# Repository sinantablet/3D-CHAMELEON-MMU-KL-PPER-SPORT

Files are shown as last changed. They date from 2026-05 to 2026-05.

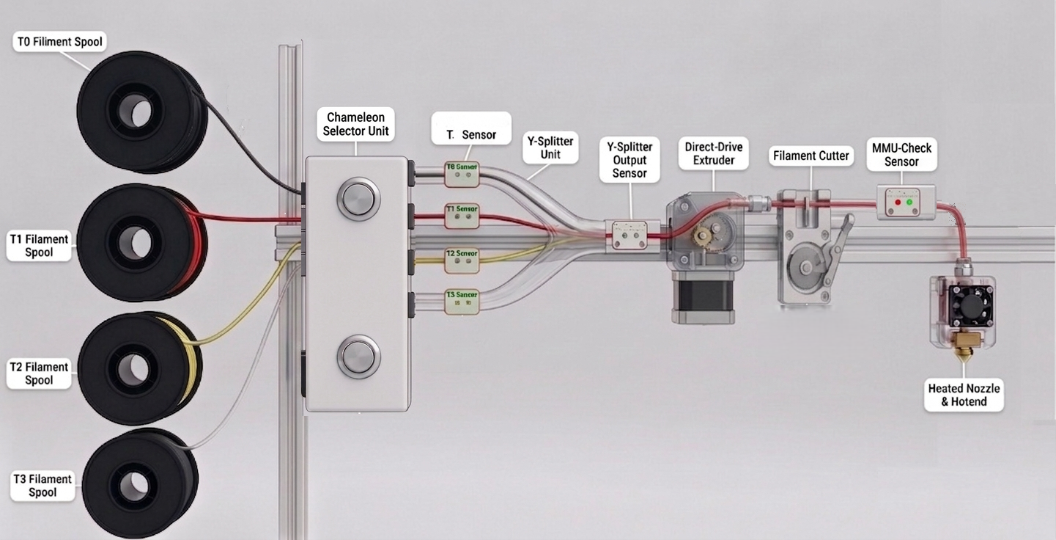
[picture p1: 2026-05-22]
mmu şema.jpg

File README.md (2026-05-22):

Klipper Tabanlı Akıllı Çoklu Filament Yönetim Sistemi (MMU)
Bu proje; stock chameleon elektronik kontrol kartına ihtiyaç duymadan, yalnızca 1 adet standart 3D yazıcı anakartı, 6 adet mikro-anahtar (switch/sensör) ve 1 adet mekanik filament kesici kullanarak Klipper üzerinde çalışan 4 renkli (T0-T3) akıllı bir filament yönetim sistemi modifikasyonudur.

Sistem; baskı güvenliğini artırmak, tıkanmaları önlemek ve renk geçişleri ile baskı sonunu tamamen otomatikleştirmek için tasarlanmıştır.

🛠 Donanım Mimarisi ve Sensör Yerleşimi
Sistemde kullanılan 6 adet optik veya mekanik siviç, anakart üzerindeki boş endstop (limit anahtarı) pinlerine bağlanır. Sensörlerin fiziksel konumları ve görevleri şu şekildedir:

A. Takım Giriş Sensörleri (4 Adet)
Konum: T0, T1, T2 ve T3 filament hatlarının tam giriş noktaları.

Görevi: Hangi takıma manuel filament yüklendiğini algılar, otomatik motor senkronizasyonunu başlatır ve ilgili hattaki filamentin bitip bitmediğini (Runout) kontrol eder.

B. Extruder Giriş Sensörü (1 Adet)
Konum: Extruder dişlilerinin hemen girişi (Hotend öncesi).

Görevi: Takımlardan gelen filamentin extruder girişine başarıyla ulaştığını doğrular.

C. Extruder Çıkış Sensörü (1 Adet)
Konum: Extruder dişlilerinin hemen çıkışı.

Görevi: Baskı esnasında gerçek zamanlı malzeme akışını izler. Motor döndüğü halde buradan filament geçmiyorsa, makara takılması veya patinaj (sıkışma) durumunu algılayarak sistemi kurtarma moduna alır.

D. Mekanik Filament Kesici (1 Adet)
Konum: Extruder mekanizmasının hemen altı (Hotend girişinin üstü).

Görevi: Baskı bittiğinde veya renk değişimlerinde filament ucunu keserek pürüzsüz bir tahliye sağlar; hotend içinde malzeme donmasını ve tıkanmayı engeller.

🚀 6 Aşamalı Akıllı Çalışma Mantığı
Sistem, Klipper makroları ve bu 6 sensörün anlık durum bilgileriyle tamamen otomatik bir döngü yönetir:

Bu sistem; çok renkli ve çok malzemeli (Multi-Material) 3D yazıcı ekosistemlerinde, baskı sürecinin kesintisiz sürmesini sağlamak, kullanıcı hatalarını en aza indirmek, donanım güvenliğini korumak ve baskı sonrasını tamamen otomatikleştirmek adına geliştirilmiş altı aşamalı bir akıllı yönetim mimarisine sahiptir.

1. Başlangıç Kalibrasyonu ve Güvenli Tahliye Protokolü

Sistem ilk enerji aktivasyonunu gerçekleştirdiğinde,Eğer besleme yollarında veya extruder gövdesinde önceden kalmış bir filament algılanırsa, olası sıkışmaları ve nozzle tıkanmalarını önlemek adına otomatik boşaltma algoritması devreye girer. Sistem, eriyik bölgedeki malzemeyi 200 derecede ve güvenli bir şekilde geri çekerek sistemi temizler ve mekanik bileşenleri başlangıç (Home) konumuna getirir.

2. Ardışık Takım Kontrolü ve Ön Yükleme Senkronizasyonu

İlk açılış rutinlerinin ardından, sistem bünyesindeki tüm filament sürücü takımları (T0, T1, T2, T3) sırayla elektronik ve mekanik teste tabi tutulur. Doğrulama sürecinde, aktif hatlardaki filamentler hızlandırılarak önceden belirlenmiş referans bekleme konumuna (hazırda bekletme noktası) otomatik olarak sürülür. Bu sayede renkli yazdırma için filament ler hazır konumda bekletiilir.

3. Dinamik Filament Sonu Algılama ve Otomatik Güvenli Park (Runout)

Baskı esnasında herhangi bir takımdaki filament tükendiğinde veya koptuğunda, hat üzerindeki mikro-sensörler durumu anlık olarak ana karta bildirir. Sistem, baskıyı kusursuz şekilde sürdürebilmek adına "Görüntü ve Pozisyon Koruma" moduna geçer: Kafayı güvenli bir koordinata park eder, ısı değerlerini optimize eder ve kullanıcıdan manuel otomotik yeni filament yüklemesi beklemek üzere sistemi askıya (Pause) alır.

4. Akıllı Manuel Besleme Sonrası Otomatik Takım Eşleştirme

Baskı askıdayken veya yazıcı hazır konumdayken, kullanıcının boşalan takımlardan herhangi birine manuel olarak filament yerleştirmesi sistem tarafından dinamik olarak izlenir. Filamentin ilgili giriş sensöründen geçmesiyle birlikte, sistem hangi takıma müdahale edildiğini akıllıca algılar, o kanala ait motor sürücüsünü aktif konuma getirir ve filamenti el gücüne gerek kalmadan otomatik olarak kavrayıp başlangıç pozisyonuna ilerletir.

5. Ekstrüzyon Sonrası Geri Besleme ve Akıllı Sıkışma Döngüsü (Anti-Jam)
Yazdırma işlemi esnasında filament varlığı, sadece giriş anında değil, extruder dişlilerinin hemen sonrasında da anlık olarak kontrol edilir. Eğer motor dönmesine rağmen extruder çıkışındaki sensörden malzeme akışı algılanmazsa, sistem bunu bir "makara takılması" veya "besleme kaçırma" hatası olarak yorumlar. Sistem, baskıyı hemen durdurmak yerine malzemeyi geri çekip tekrar ileri sürmeyi deneyerek 2 kez otomatik yükleme döngüsü başlatır. Hata çözülmezse donanım güvenliği için sistemi korumalı duraklatma moduna alır. sorun giderildikten sonra baskıya devem edilebilir.

6. Otomatik Baskı Sonu Boşaltma ve Sonraki Baskıya Hazırlık Protokolü
Baskı başarıyla tamamlandığı an, sistem eritme potasını ve filament yolunu bir sonraki işe sıfır hata ile hazırlamak için TOOL_OUT makrosunu tetikler. Bu protokol sırasıyla; filament kesme (filament cut) mekanizmasını çalıştırır, extruder içinde kalan erimiş veya kesilmiş malzemeyi tahliye eder (extruder unload) ve son olarak aktif olan takım hangisi ise o takıma ait filamenti güvenli başlangıç (home) konumuna geri çeker. Böylece bir sonraki baskı öncesinde elle müdahaleye gerek kalmaz.

Filament Cut: Mekanik kesici aktif hat üzerindeki filamenti keser.

Extruder Unload: Extruder içinde kalan parça eritilerek tahliye edilir.

Tool Park: Aktif olan takım hangisi ise, o hattın filamenti bir sonraki baskıya hazır olmak üzere kendi başlangıç konumuna geri çekilir.

🎛 Dilimleyici (Slicer) Kurulumu

Sistemin baskı ilk başladığında donanımı ve filament yollarını senkronize eden akıllı protokolümüz TOOL_INIT makrosudur.
(OrcaSlicer, PrusaSlicer, Bambu Studio vb.) Printer Settings -> start g-code  ( TOOL_INIT )
Sistemin baskı sonu otomasyonunu tetikleyebilmesi için dilimleyici yazılımınızın (OrcaSlicer, PrusaSlicer, Bambu Studio vb.) Printer Settings -> end g-code  ( TOOL_OUT  TS0 )

yazıcı ayarlarından -> çoklu malzeme -> tek extruder çoklu mazleme kurulumu
çoklu mazleme sekmesinden -> pirme kulesini aktif edin.

🎛Yazıcı ayarı
printer.cfg dosyanızın ilk satırna  
[include chameleon.cfg] 
ekleyin

######################################################       ####################################################################

                                                  MAKRO AYAR VE DEĞERLERİ

--------------------------------------------------------------------------------

pin çıkışlarını kendi bord unuza göe ayarlayınız

[manual_stepper selector]
step_pin: nano:PE0
dir_pin: nano:PB9
microsteps: 1
rotation_distance: 2
enable_pin: !nano:PE1
endstop_pin: !nano:PA2  
velocity: 20      
accel: 20      
position_endstop: 15

[manual_stepper chameleon]
step_pin: nano:PB5
dir_pin: nano:PB4
microsteps: 16
rotation_distance: 41
enable_pin: !nano:PB8
endstop_pin: nano:PE6   ( bu pin önemli CHAMELEON_EXTRUDER_SMART_LOAD buradaki pine edn step yaparak filament konumu ayaralıyor)
position_endstop: 0

sensör pinleriniz anakartınıza göre ayarlayınız..

[filament_switch_sensor tool_0_sensor]
switch_pin: nano:PA15
pause_on_runout: True

[filament_switch_sensor tool_1_sensor]
switch_pin: nano:PA12
pause_on_runout: True

[filament_switch_sensor tool_2_sensor]
switch_pin: nano:PA14
pause_on_runout: True

[filament_switch_sensor tool_2_sensor]
switch_pin: nano:PA13
pause_on_runout: True

[filament_switch_sensor mmu_check]
switch_pin: nano:PB2
pause_on_runout: False

--------------------------------------------------------------------------------

[gcode_macro TOOL_INIT]
description: Homes the tool selector. Needed before any tool change.
variable_tool: 0
variable_ysplit_distance: 100
variable_chameleon_speed: 40
variable_chameleon_acc: 40
gcode:
  MANUAL_STEPPER STEPPER=selector SET_POSITION=0 
  MANUAL_STEPPER STEPPER=selector MOVE=-1.40
  MANUAL_STEPPER STEPPER=selector SET_POSITION=0 
  MANUAL_STEPPER STEPPER=selector MOVE=0.12
  MANUAL_STEPPER STEPPER=selector SET_POSITION=0 
  MANUAL_STEPPER STEPPER=chameleon SET_POSITION=0

---->variable_ysplit_distance: 100  dğerini filamnet hub ölçünüze göre ayarlaryın yspit

----->MANUAL_STEPPER STEPPER=selector MOVE=-1.40      ( bu değeri elle konsola deneyerek girnizi -1 den  -2 ye kadar deneyin selktör şaftı üzerindeki çıkıntının paralel konumu sizin başlangıç açınız olacakrtır.

------------------------------------------------------------------------------------------

[gcode_macro FILAMENT_CUT]
description: Filament kesme, tamamen otomatik güvenli Z
gcode:
  {% set F = params.F|default(6000)|int %}
  {% set current_z = printer.toolhead.position.z %}
  {% set max_model_z = params.model_z|default(current_z)|float %}
  {% set Z_safe = [current_z + 5, max_model_z + 5]|max %}

  G90 
  G1 Z{Z_safe} F3000
  G1 X290 Y290 F{F}

  G92 E0
  G1 E-2 F300
  G92 E0
  G1 E-90 F2500
  G92 E0; 
  G1 X300 Y290 F4000  
  G1 X250 Y299 F4000
  G1 X300 Y299 F4000
  G1 X290 Y290 F4000
  M117 "Filament kesildi"
  G92 E0  

filamnet kesme konumunuzu ve filamnet kesiciye çekme ölçünüzü yazıcınıza yapısına göre ayarlayınız

----->  G1 E-90 F2500 
nuzell ucu ile kesici bıcak arasındaki mesafenizi giriniz bu değer filamet ucundan 2 mm olacak şekilde ayarlanırsa filameet atığınız azalır

kesme konumu ve kesme hareketleri
---->G1 X290 Y290 F{F}

  G1 X300 Y290 F4000  
  G1 X250 Y299 F4000
  G1 X300 Y299 F4000
  G1 X290 Y290 F4000

  -----------------------------------------------------------------------------

[gcode_macro TOOL_SELECT]
gcode:
  {% set TOOL = params.TOOL|int %}
  {% set SELECTOR_SPEED = 20 %}
  M117 "Setting tool to TOOL{TOOL}"

  {% if TOOL == 0 %}
    MANUAL_STEPPER stepper=selector MOVE=0
  {% elif TOOL == 1 %}
    MANUAL_STEPPER stepper=selector MOVE=-4.5
  {% elif TOOL == 2 %}
    MANUAL_STEPPER stepper=selector MOVE=-9.5
  {% elif TOOL == 3 %}
    MANUAL_STEPPER stepper=selector MOVE=-12.5
  {% endif %}
  SET_GCODE_VARIABLE MACRO=TOOL_INIT VARIABLE=tool VALUE={TOOL}

her takımın konumunu konsoldan  MANUAL_STEPPER stepper=selector MOVE=0  manuel olarakdeğer girerek tespit edin
t0 t1 t2 t3 takım yolu açılarını bulunuz ve sisteme kayıt ediniz. açı değerleinin sağlıklı olduğundan emin olun filamneti yol seçimleri belirlediğiniz bu değerlere göre yapılacaktır.

--->MANUAL_STEPPER stepper=selector MOVE=0
--->MANUAL_STEPPER stepper=selector MOVE=-4.5
--->MANUAL_STEPPER stepper=selector MOVE=-9.5
--->MANUAL_STEPPER stepper=selector MOVE=-12.5

----------------------------------------------------------------------------------------------------------------------------------

[gcode_macro TOOL_FREE]
gcode:
  {% set TOOL = params.TOOL|int %}
   M117 "Free filament path for tool {TOOL}"
  {% if TOOL == 0 %}
    MANUAL_STEPPER stepper=selector MOVE=-12.5
  {% elif TOOL == 1 %}
    MANUAL_STEPPER stepper=selector MOVE=-9.5
  {% elif TOOL == 2 %}
    MANUAL_STEPPER stepper=selector MOVE=0
  {% elif TOOL == 3 %}
    MANUAL_STEPPER stepper=selector MOVE=-4.5
  {% endif %}

TOOL_SELECT makrosune göre  ters örüntülü  olarak değerleri girebilirsiniz.

-----------------------------------------------------------------------------------------------------------------------

[gcode_macro CHAMELEON_EXTRUDER_SMART_LOAD]

    {% if TOOL == 0 or TOOL == 1 %}
        MANUAL_STEPPER stepper=chameleon MOVE=-95 speed={SPEED} accel={ACC}
        MANUAL_STEPPER stepper=chameleon SET_POSITION=0
    {% else %}
        MANUAL_STEPPER stepper=chameleon MOVE=95 speed={SPEED} accel={ACC}
        MANUAL_STEPPER stepper=chameleon SET_POSITION=0
    {% endif %}
    
---->MANUAL_STEPPER stepper=chameleon MOVE=-95 speed={SPEED} accel={ACC}
---->MANUAL_STEPPER stepper=chameleon MOVE=95 speed={SPEED} accel={ACC}

[gcode_macro TOOL_INIT] makrosu içindeki variable_ysplit_distance: 100 değerinden 5 ila 10 puan düşük giriniz

----------------------------------------------------------------------------------------------------------------------------

[gcode_macro EXTRUDER_UNLOAD]

----> G1 E-42 F2000 
filamnet kesici ile extuder dişilileri arasındaki mesafenizi giriniz ölçünüzden 10 puan falza giremniz yaralı olacaktır. örnek kesici ile dişili arasında 40mm ölçüm yaptı iseniz 50 mm giriniz

----------------------------------------------------------------------------------------------------------------------------------
[gcode_macro EXTRUDER_LOAD]

---->G1 E108 F2000  extuder ile nuzel arasındakş  ölçünüzü girniz değerin tam olması filamnet  çapaklanmasını azaltacaktır normal ölçünüzden 1mm düşük girmenizi tavsiye ederim

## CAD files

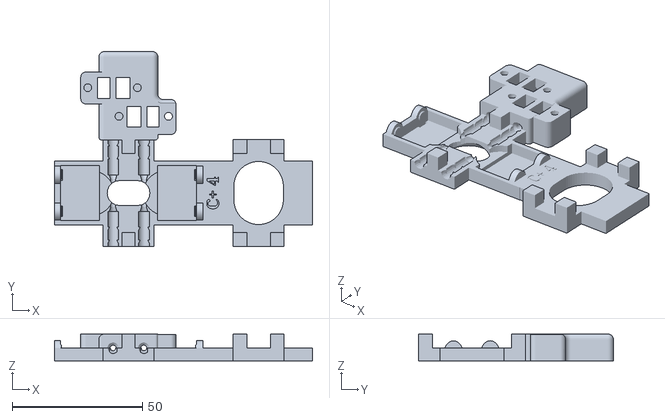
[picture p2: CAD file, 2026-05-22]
3D CAHMELON c part1.stl
99.1 x 74.8 x 10.3

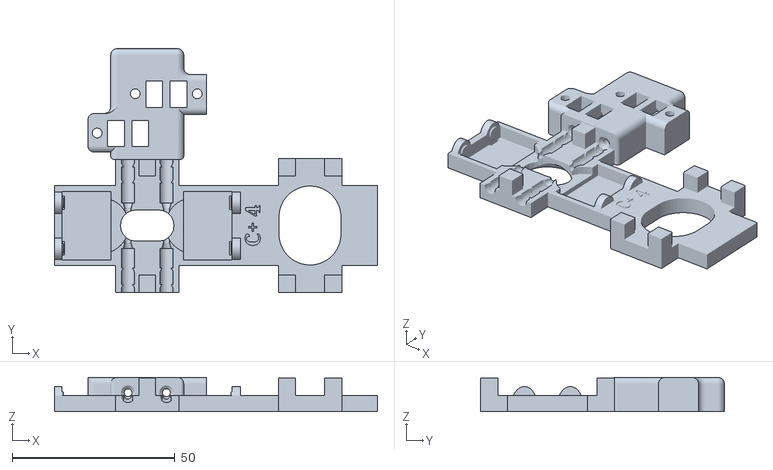
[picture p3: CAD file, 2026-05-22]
3D CAHMELON c part2.stl
99.1 x 74.8 x 10.5

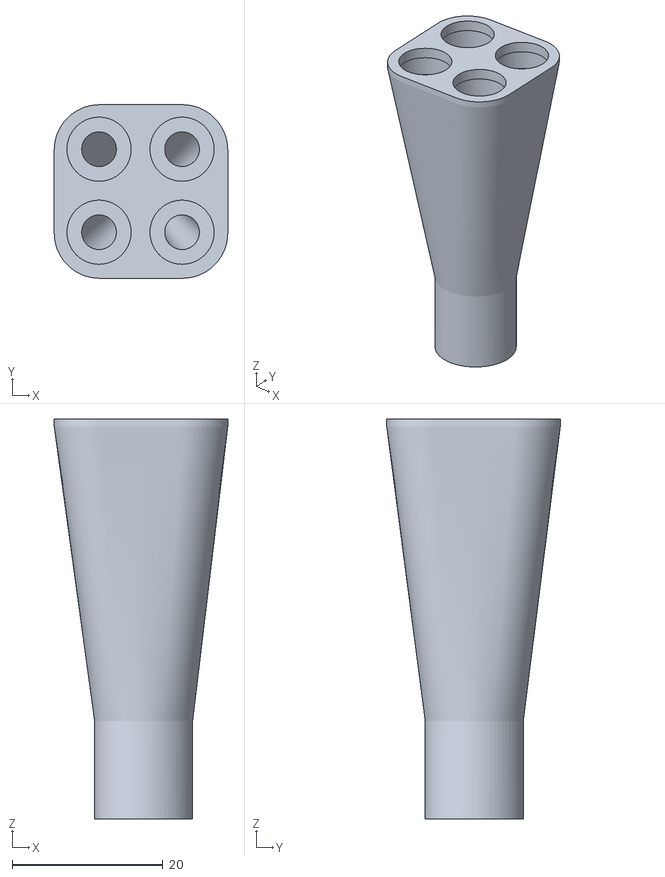
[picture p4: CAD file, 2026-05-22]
y siplit 50mm.stl
23.0 x 23.0 x 53.0

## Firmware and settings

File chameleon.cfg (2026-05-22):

#############################
# Manual Stepper Tanımlamaları
#############################

[manual_stepper selector]
step_pin: nano:PE0
dir_pin: nano:PB9
microsteps: 1
rotation_distance: 2
enable_pin: !nano:PE1
endstop_pin: !nano:PA2  
velocity: 20      
accel: 20      
position_endstop: 15

[manual_stepper chameleon]
step_pin: nano:PB5
dir_pin: nano:PB4
microsteps: 16
rotation_distance: 41
enable_pin: !nano:PB8
endstop_pin: nano:PE6
position_endstop: 0


#############################
# takım seçici sıfırlama
#############################

[delayed_gcode startup_move]
initial_duration: 2
gcode:
    
    MANUAL_STEPPER STEPPER=selector MOVE=15
    MANUAL_STEPPER STEPPER=selector SET_POSITION=0
    SAFE_RECOVERY_STARTUP
    TS0
    MANUAL_STEPPER STEPPER=chameleon SET_POSITION=0
    


#############################
# Filament ekran durum bildirgesi
#############################


[gcode_macro FILAMENT_INSERTED]
description: "Resumes the print when filament is inserted"
gcode:
    M117 "Filament detected! Resuming print..."
    RESUME


#############################
# Filament Sensör Tanımlamaları
#############################

[filament_switch_sensor tool_0_sensor]
switch_pin: nano:PA15
pause_on_runout: True
runout_gcode:
    M117 "Filament Runout on Tool 0!"
insert_gcode:
    M117 "Filament inserted!"
    {% set state = printer.print_stats.state %}
    {% if state == "standby" %}
        M117 "Running smart load..."
        TS0
        CHAMELEON_EXTRUDER_SMART_LOAD
        TS0
    {% else %}
        M117 "Printing or paused, ignoring sensor trigger."
    {% endif %}



[filament_switch_sensor tool_1_sensor]
switch_pin: nano:PA12
pause_on_runout: True
runout_gcode:
    M117 "Filament Runout on Tool 1!"
insert_gcode:
    M117 "Filament inserted!"
    {% set state = printer.print_stats.state %}
    {% if state == "standby" %}
        M117 "Running smart load..."
        TS1
        CHAMELEON_EXTRUDER_SMART_LOAD
        TS0
    {% else %}
        M117 "Printing or paused, ignoring sensor trigger."
    {% endif %}




[filament_switch_sensor tool_2_sensor]
switch_pin: nano:PA11
pause_on_runout: True
runout_gcode:
    M117 "Filament Runout on Tool 2!"
insert_gcode:
    M117 "Filament inserted!"
    {% set state = printer.print_stats.state %}
    {% if state == "standby" %}
        M117 "Running smart load..."
        TS2
        CHAMELEON_EXTRUDER_SMART_LOAD
        TS0
    {% else %}
        M117 "Printing or paused, ignoring sensor trigger."
    {% endif %}



[filament_switch_sensor tool_3_sensor]
switch_pin: nano:PC4
pause_on_runout: True
runout_gcode:
    M117 "Filament Runout on Tool 3!"
insert_gcode:
    M117 "Filament inserted!"
    {% set state = printer.print_stats.state %}
    {% if state == "standby" %}
        M117 "Running smart load..."
        TS3
        CHAMELEON_EXTRUDER_SMART_LOAD
        TS0
    {% else %}
        M117 "Printing or paused, ignoring sensor trigger."
    {% endif %}





#############################
# MMU FİLAMNET CONTROL SYSTEM (MEKANİK KORUMALI SÜRÜM)
#############################

[filament_switch_sensor mmu_check]
switch_pin: nano:PB2
pause_on_runout: False

[gcode_macro MOVE_AND_CHECK]
description: Filamenti anında kontrol eder, yoksa kurtarma dener, yine olmazsa PAUSE yapar
variable_load_retry: 0
gcode:
  QUERY_FILAMENT_SENSOR SENSOR=mmu_check
  
  {% set target_tool = printer["gcode_macro TOOL_INIT"].tool | int %}
  {% set current_retry = printer["gcode_macro MOVE_AND_CHECK"].load_retry | int %}
  {% set retry_limit = 3 %} 
  {% set speed = printer["gcode_macro TOOL_INIT"].chameleon_speed %}

  # 1. DURUM: FİLAMAN ALGILANDI
  {% if printer["filament_switch_sensor mmu_check"].filament_detected %}
    M117 MMU icin Filament gecisi saglandi.
    SET_GCODE_VARIABLE MACRO=MOVE_AND_CHECK VARIABLE=load_retry VALUE=0

  # 2. DURUM: FİLAMAN YOK
  {% else %}
    {% if current_retry < retry_limit %}
      {action_respond_info("HATA: Filament algilanamadi! Güvenli Kurtarma Denemesi %d/%d" % (current_retry + 1, retry_limit))}
      SET_GCODE_VARIABLE MACRO=MOVE_AND_CHECK VARIABLE=load_retry VALUE={current_retry + 1}
      
      # --- KULEDE MEKANİK GÜVENLİ KURTARMA ---
      EXTRUDER_UNLOAD                             
      TOOL_SELECT TOOL={target_tool}              
      
      # Chameleon Mikro Geri Çekme (Filamenti dişliden kaçırmadan sadece 25mm gevşetir)
      MANUAL_STEPPER STEPPER=chameleon SET_POSITION=0
      {% if target_tool == 0 or target_tool == 1 %}
          MANUAL_STEPPER stepper=chameleon MOVE=-25 SPEED={speed}
          MANUAL_STEPPER STEPPER=chameleon SET_POSITION=0
          MANUAL_STEPPER stepper=chameleon MOVE=40 SPEED={speed} 
      {% else %}
          MANUAL_STEPPER stepper=chameleon MOVE=25 SPEED={speed}
          MANUAL_STEPPER STEPPER=chameleon SET_POSITION=0
          MANUAL_STEPPER stepper=chameleon MOVE=-40 SPEED={speed} 
      {% endif %}
      
      # Tekrar Kavrama ve Extruder'a Güvenli Teslimat
      G92 E0
      G1 E8 F300 
      TOOL_FREE TOOL={target_tool}                
      EXTRUDER_LOAD                               
      M400                                        
      
      UPDATE_DELAYED_GCODE ID=_RETRY_TRIGGER DURATION=0.1

    # 3. DURUM: 3 DENEME DE BAŞARISIZ OLDU -> KESİN PAUSE
    {% else %}
      {action_respond_info("HATA: 3 otomatik deneme basarisiz! Filament algilanamadi. Yazdirma Duraklatiliyor...")}
      SET_GCODE_VARIABLE MACRO=MOVE_AND_CHECK VARIABLE=load_retry VALUE=0
      
      {% if "xyz" in printer.toolhead.homed_axes %}
        PAUSE
      {% else %} 
        M117 HATA: MMU için Filament Yüklenemedi.
        PAUSE
      {% endif %} 
    {% endif %}
  {% endif %}

[delayed_gcode _RETRY_TRIGGER]
gcode:
  MOVE_AND_CHECK









  
#############################
# G-Code Makroları
#############################

[gcode_macro TOOL_INIT]
description: Homes the tool selector. Needed before any tool change.
variable_tool: 0
variable_ysplit_distance: 100
variable_chameleon_speed: 40
variable_chameleon_acc: 40
gcode:
  MANUAL_STEPPER STEPPER=selector SET_POSITION=0 
  MANUAL_STEPPER STEPPER=selector MOVE=-1.40
  MANUAL_STEPPER STEPPER=selector SET_POSITION=0 
  MANUAL_STEPPER STEPPER=selector MOVE=0.12
  MANUAL_STEPPER STEPPER=selector SET_POSITION=0 
  MANUAL_STEPPER STEPPER=chameleon SET_POSITION=0




  {% if printer["gcode_macro TOOL_INIT"].tool == 0 %}
    M117 "Mevcut takım korunuyor"
  {% else %}
    M117 "Aktif takım: {printer["gcode_macro TOOL_INIT"].tool}"
  {% endif %}


  
#############################
# filamnet gps
#############################

[gcode_macro SMART_INITIAL_LOAD]
gcode:
    M117 Filamentler Hizalanıyor...
    TS0
    CHAMELEON_UNLOAD 
    CHAMELEON_EXTRUDER_SMART_LOAD 
    TS1
    CHAMELEON_UNLOAD
    CHAMELEON_EXTRUDER_SMART_LOAD
    TS2
    CHAMELEON_UNLOAD
    CHAMELEON_EXTRUDER_SMART_LOAD
    TS3
    CHAMELEON_UNLOAD
    CHAMELEON_EXTRUDER_SMART_LOAD
    M117 Tüm Filamentler Hazır ve Park Edildi!



#############################
# nuuzel temizleme konumu
#############################



[gcode_macro WIPE]
description: Nozzle temizleme
gcode:
  {% set F = params.F|default(6000)|int %}
  {% set current_z = printer.toolhead.position.z %}
  {% set max_model_z = params.model_z|default(current_z)|float %}
  {% set Z_safe = [current_z + 5, max_model_z + 5]|max %}
  G90 
  G1 Z{Z_safe} F3000
  G1 X290 Y290 F{F}
  {% for _ in range(3) %}  ; 3 kez tekrarla
  {% endfor %}
  G92 E0
 




#############################
# filamet kesme konumu 
#############################


[gcode_macro FILAMENT_CUT]
description: Filament kesme, tamamen otomatik güvenli Z
gcode:
  {% set F = params.F|default(6000)|int %}
  {% set current_z = printer.toolhead.position.z %}
  {% set max_model_z = params.model_z|default(current_z)|float %}
  {% set Z_safe = [current_z + 5, max_model_z + 5]|max %}

  
  G90 
  G1 Z{Z_safe} F3000
  G1 X290 Y290 F{F}

  G92 E0
  G1 E-2 F300
  G92 E0
  G1 E-90 F2500
  G92 E0; 
  G1 X300 Y290 F4000  
  G1 X250 Y299 F4000
  G1 X300 Y299 F4000
  G1 X290 Y290 F4000
  M117 "Filament kesildi"
  G92 E0  





#############################
# takım seçici konum paremetresi
#############################

[gcode_macro TS0]
gcode:
  TOOL_SELECT TOOL=0

[gcode_macro TS1]
gcode:
  TOOL_SELECT TOOL=1

[gcode_macro TS2]
gcode:
  TOOL_SELECT TOOL=2

[gcode_macro TS3]
gcode:
  TOOL_SELECT TOOL=3


#############################
# takkım seçici
#############################


[gcode_macro TOOL_SELECT]
gcode:
  {% set TOOL = params.TOOL|int %}
  {% set SELECTOR_SPEED = 20 %}
  M117 "Setting tool to TOOL{TOOL}"
  
 
  {% if TOOL == 0 %}
    MANUAL_STEPPER stepper=selector MOVE=0
  {% elif TOOL == 1 %}
    MANUAL_STEPPER stepper=selector MOVE=-4.5
  {% elif TOOL == 2 %}
    MANUAL_STEPPER stepper=selector MOVE=-9.5
  {% elif TOOL == 3 %}
    MANUAL_STEPPER stepper=selector MOVE=-12.5
  {% endif %}
  SET_GCODE_VARIABLE MACRO=TOOL_INIT VARIABLE=tool VALUE={TOOL}
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
